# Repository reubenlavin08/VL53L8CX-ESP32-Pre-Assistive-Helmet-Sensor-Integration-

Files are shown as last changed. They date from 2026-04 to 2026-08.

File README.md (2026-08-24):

<h1 align="center">Assistive Helmet</h1>

<p align="center">
  <em>A helmet that answers what the white cane can't: what's at head height, what's approaching, and where exactly the thing you want is.</em>
</p>

<p align="center">
  
  
  
  
  
</p>

---

<p align="center">
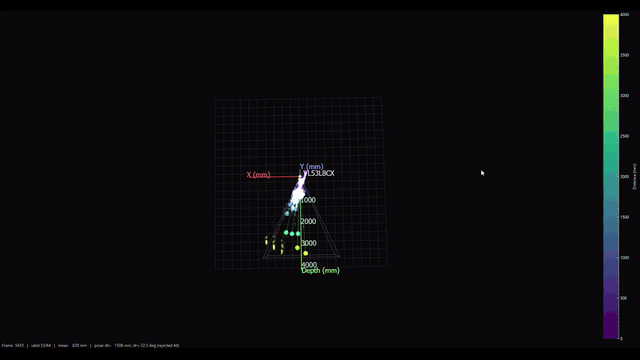
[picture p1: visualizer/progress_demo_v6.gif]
Live 3D depth scan building as the helmet pans
  
</p>
<p align="center"><em>The helmet's two depth sensors building a live 3D scan as the head pans. Demo video of the full system: coming with the field-test release.</em></p>

---

## Why

Blind pedestrians with a cane or a guide dog still take head-level hits — 13% report one at least monthly, and the number is the same for cane and dog users. GPS says "you have arrived" from 5–20 meters away, often on the wrong side of the building. And there is no way to ask the street a question. This helmet is a research prototype aimed at those three gaps. It stays silent until it matters, it never guides anywhere you didn't choose, and the cane stays in charge of the ground.

It is not a mobility aid and not a substitute for a white cane, a guide dog, or O&M training.

## What it does

**Protect** — hazards above cane height, silent by default:
- Tiered voice: nothing → "chair, left" on change → "stop stop" directive that interrupts everything
- Proximity as a tick that speeds with time-to-collision — panned to the hazard's direction — not numbers
- Gravity-referenced head-clearance watch: "low clearance, duck" computed in the world frame from live IMU attitude, so it works mid-stride at any head pitch
- Three temple motors with a walkable-corridor mode: silence when centered, pulses only as you drift toward a wall
- Speech gates itself during fast head turns (a stale "left" mid-scan is worse than silence)
- If the helmet falls, it says so and repeats until picked up

**Guide** — to a target you choose, never a guess:
- "scan doors" → "door one, twelve o'clock, about six steps; door two…" → pick one → Microsoft Soundscape's actual audio beacon (their open-sourced assets) leads you, arrival melody at one meter
- "find exit" → OCR scans as you pan, locks the beacon on the matched word in world coordinates — it keeps working when you look away
- Distances spoken in your calibrated steps, not meters

**Answer** — on demand only:
- "what's around" → one item per sector, terse; ask again for ranges; a third time for a full scene description
- "describe" / "what's in my hand" → a vision-language model answers in one sentence, and says "I can't see that clearly" rather than guess — blind users can't detect a wrong answer, so the system never bluffs
- "read that" → speaks the dominant text in view
- All of it by voice (wake word "Iris"), keyboard, or a double-tap on the shell

**The Iris phone app** — the whole rig is monitored and driven from a phone
with zero App Store involvement: a PWA (`Add to Home Screen` in Safari)
that launches fullscreen under its own icon. Live annotated video at max
size with translucent controls placed in the letterbox space, a status bar
showing what Iris last said, and touch buttons (around / describe / mute /
flag) feeding the same command queue as voice. An always-on launcher
(`camera/launcher.py`, runs at login) means the icon works even when the
software isn't running — it shows a Start button, boots the whole stack,
and hands over to the live view. The desktop window mirrors the same UI.

## The numbers

| What | Measured |
|---|---|
| ToF↔camera extrinsic calibration | 5.5 mm rms, 1.15° from CAD, 39 poses |
| Full CV pipeline on the field laptop | 27 fps segmentation, 114 ms open-vocabulary door scan |
| Scene OCR (cloud) | 1.3–2.4 s, per-word bearings |
| Scene description (cloud VLM) | 2–6 s, abstention-prompted |
| Head-turn gate estimator | tracks 191°/s, decays to 0 on stop |
| False positives | logged per session as FP/hour — the metric that kills devices like this |

## How it works

Two $6 ST VL53L8CX time-of-flight sensors (seam-abutted for a ~90° depth field) and a fisheye camera on a bike helmet, an ESP32-S3 streaming depth + IMU attitude over WiFi, and a laptop fusing it: YOLO segmentation ranges each object by the depth zones its mask claims; an open-vocabulary detector finds doors on demand; cloud models handle text and description. Output is a tier engine modeled on assistive-audio research — Microsoft Soundscape's design language, fighter-aviation callout structure, bat-inspired time-to-collision coding — through open-ear audio and temple haptics. Every alert, override, and near-miss is logged; a hush within ten seconds of an alert counts as a false-positive vote against it.

## Built on evidence

- 30+ commissioned research syntheses in [`docs/research-sources/`](docs/research-sources) — what blind users actually ask for, why every commercial wearable in this space died, and the implementation literature feature by feature
- Design constants read from [Microsoft Soundscape's source](docs/soundscape-reference), not its marketing; competitor patents (.lumen, Glidance, Toyota, Apple) mined for their engineering
- Methods published as prior art so they stay free: [defensive publication](docs/DEFENSIVE-PUBLICATION.md)
- The full build story, failures first: [`docs/DEVLOG.md`](docs/DEVLOG.md)

## Honest limitations

Glass is invisible to the depth sensors (the cane covers it — by design). Bright-sun range is untested and probably poor. Overhead coverage leans on natural gait pitch with the current sensor aim. Cloud features need connectivity (the field rig runs on a phone hotspot). One wearer so far.

Parts of the research synthesis and code were built with Claude as an engineering copilot; every measurement and design decision above was verified on the bench.

---

# Technical reference

## What it does

An ESP32-S3 talks to an **ST VL53L8CX** time-of-flight sensor over I²C, uploads ST's ULD firmware to the chip on boot, and streams the 64-zone depth grid as compact `DATA:d0,d1,…,d63\n` lines over USB-serial at 15 Hz. A Python visualiser reads those lines and renders the scene live — animated ToF rays from the sensor body, a side colour-bar with the distance scale, a Kabsch-based 6-DOF pose estimator, and a world-frame point memory that builds a rolling 3D scan as the sensor sweeps.

---

## Iteration gallery — v1 → v6 at a glance

<table align="center">
  <tr>
    <td align="center" width="25%">
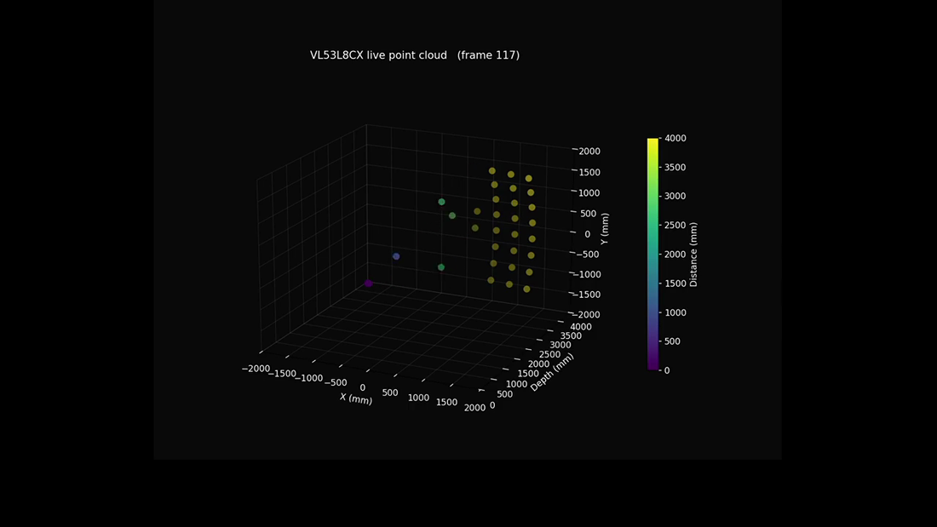
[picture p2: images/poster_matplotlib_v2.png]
v1/v2 matplotlib
      
      <br/><strong>v1 / v2 — matplotlib</strong>
      <br/><sub>first scatter; flicker / drift fixed by v2</sub>
    </td>
    <td align="center" width="25%">
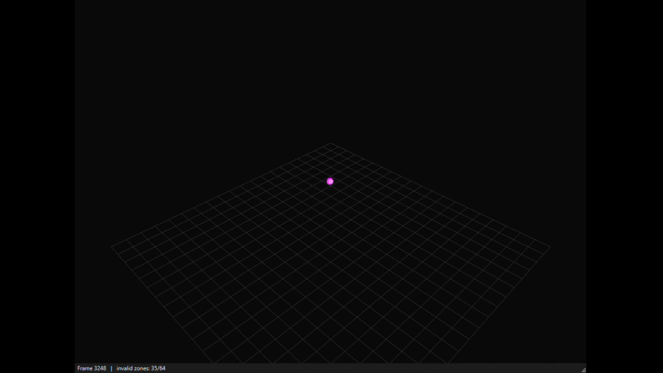
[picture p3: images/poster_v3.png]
v3 PyQtGraph
      
      <br/><strong>v3 — PyQtGraph + threaded</strong>
      <br/><sub>GPU rotation; drain-first pipeline</sub>
    </td>
    <td align="center" width="25%">
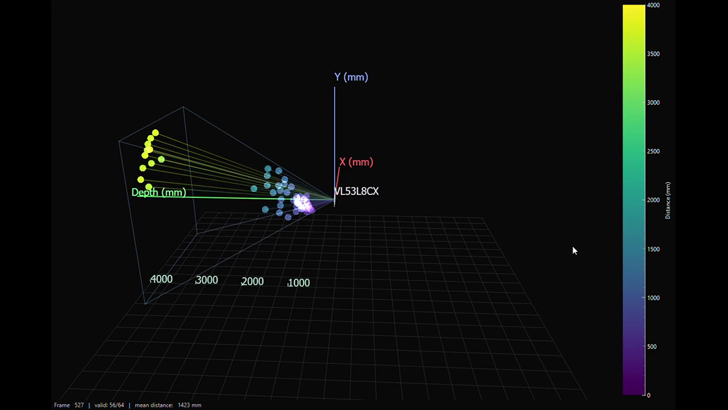
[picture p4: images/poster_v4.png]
v4 scientific look + ToF beams
      
      <br/><strong>v4 — scientific look + ToF beams</strong>
      <br/><sub>colour bar, axes, sensor body, frustum</sub>
    </td>
    <td align="center" width="25%">
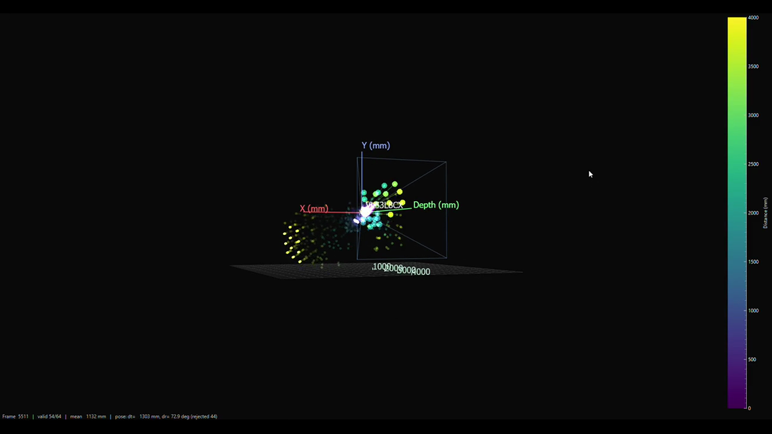
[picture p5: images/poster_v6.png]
v6 world-frame memory
      
      <br/><strong>v6 — world-frame memory</strong>
      <br/><sub>+ Kabsch 6-DOF pose, fading trail</sub>
    </td>
  </tr>
</table>

---

## The hardware

<p align="center">
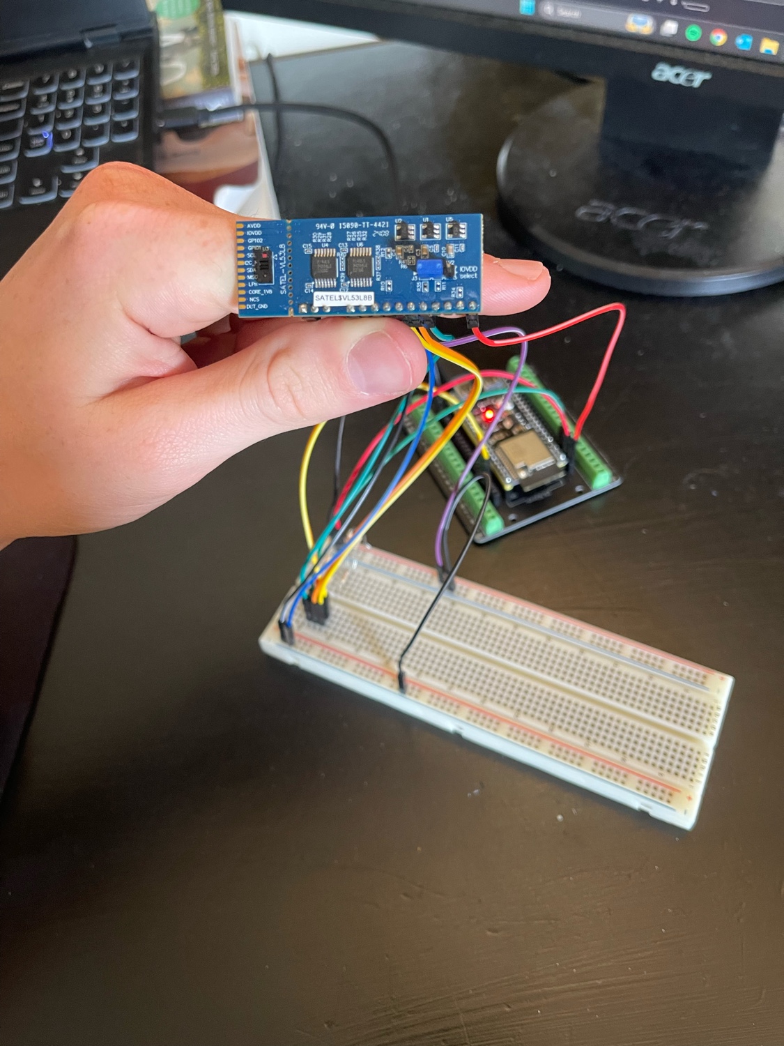
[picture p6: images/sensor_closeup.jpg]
SATEL-VL53L8CX close-up
  
  &nbsp;&nbsp;
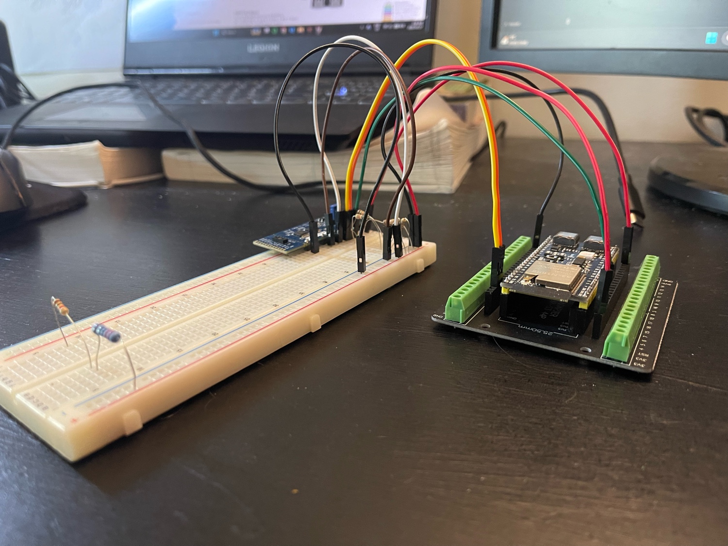
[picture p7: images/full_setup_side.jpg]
Breadboard side view
  
</p>
<p align="center">
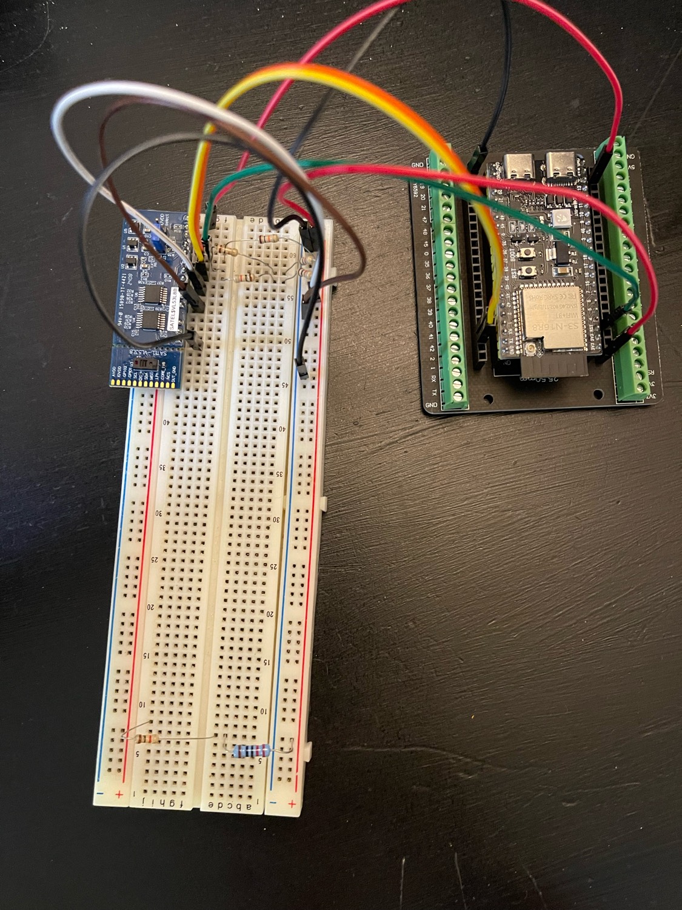
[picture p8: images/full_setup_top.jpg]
Full circuit top-down
  
</p>
<p align="center"><em>SATEL-VL53L8CX breakout on an ESP32-S3-DevKitC-1. 2 × 1 kΩ pull-ups in series on each I²C line, 10 kΩ on PWREN, sensor powered from 3.3 V.</em></p>

---

## The transformation — matplotlib → PyQtGraph

The visualiser was rewritten three times in a single weekend. The first cut used matplotlib `mplot3d`; mouse rotation was sluggish and the renderer was always one frame stale. v3 swapped in PyQtGraph + OpenGL, threaded the serial reader, and flipped the drain order. The clip below is 3 seconds of the original, then 7 seconds of v3:

<p align="center">
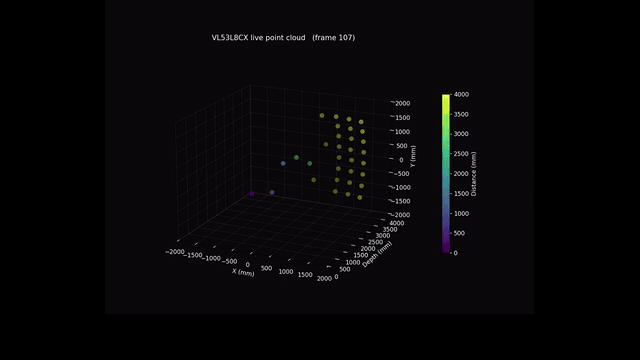
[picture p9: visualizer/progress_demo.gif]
matplotlib v2 vs PyQtGraph v3 before/after
  
</p>
<p align="center">
  <em>Before / after — the same data on the same hardware, rendered through two different pipelines.</em>
  <br/>
  <sub><a href="visualizer/progress_demo.mp4">▶ HD MP4 (10 s, 134 KB)</a></sub>
</p>

| | v1 / v2 (matplotlib) | v3 (PyQtGraph) |
|---|---|---|
| Renderer | software-rendered `mplot3d` | GPU `GLViewWidget` + OpenGL |
| Mouse rotation | sluggish (GUI thread starved) | native — pan/zoom decoupled from data |
| Serial read | on GUI thread; 1 s timeout could stall | dedicated `QThread` with Qt signal |
| Drain order | read → process → drain (always one stale) | drain first, render newest valid frame |
| Smoothing | EMA α = 0.3 (~900 ms settle) | EMA α = 0.6 (~300 ms settle) |
| Invalid zones | drawn as a phantom 4 m back-wall | masked to NaN, drawn transparent |

---

## Architecture

```mermaid
flowchart LR
    A[VL53L8CX SPADs<br/>8×8 zones] -- I²C @ 1 MHz --> B[ESP32-S3<br/>ESP-IDF firmware]
    B -- USB-serial<br/>DATA:… 15 Hz --> C[Python<br/>SerialReader QThread]
    C --> D[Kabsch<br/>pose estimator]
    C --> E[EMA + NaN mask]
    D --> F[PyQtGraph + OpenGL<br/>GLViewWidget]
    E --> F
    F --> G[Live 3D scene<br/>+ world-frame memory]
```

---

## What you're looking at

<p align="center">
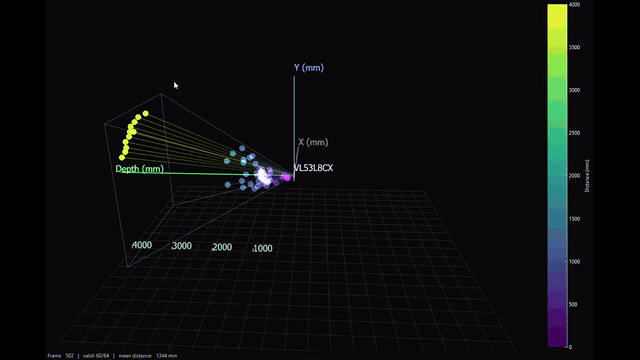
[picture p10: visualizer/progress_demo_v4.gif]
v4 visualiser elements in motion
  
</p>
<p align="center">
  <em>v4 in motion — sensor body, FoV frustum, animated ToF beams. Same scene as v6 but without the world-frame memory layer, so each element is easier to identify in isolation.</em>
  <br/>
  <sub><a href="visualizer/progress_demo_v4.mp4">▶ HD MP4 (5 s, 182 KB)</a></sub>
</p>

| Element | What it is |
|---|---|
| **64 bright dots in a cone** | Live measurements, one per zone, coloured by distance (viridis: purple = close, yellow = far). |
| **Animated coloured beams from the sensor** | One ToF ray per zone, faded from the lens out to its endpoint, in the same hue as the point. They pulse with the live data — physically what a multizone ToF sensor is doing. |
| **Faded surrounding cloud** *(v6)* | Past observations in **world frame**, transformed back into the current sensor frame each tick and faded by age (~6 s memory). As you rotate, they slide off to the side instead of staying glued to the front. |
| **Yellow line behind the sensor** *(v5+)* | Estimated 6-DOF trajectory of the sensor's origin (last ~5 s), per-vertex alpha-faded so old segments disappear. |
| **Sensor body + lens ring at origin** | Flat dark rectangle modelling the SATEL-VL53L8CX face, with a bright lens circle and "VL53L8CX" label. |
| **Pale frustum** | The sensor's actual 45° × 45° field of view (per ST datasheet — 65° diagonal). |
| **Side colour bar** | Distance scale in mm. |
| **Status bar** | Live frame count, valid-zones / 64, mean valid distance, cumulative pose translation + rotation, and the per-frame rejection count. |

---

## Iteration story — v1 → v6

| Version | What it added | Why |
|---|---|---|
| **v1** | First working matplotlib 3D scatter. | Get *anything* on screen. |
| **v2** | In-place scatter update; serial-buffer drain; EMA smoothing. | Killed flicker, stale data, noise jitter. |
| **v3** | PyQtGraph + OpenGL; threaded serial; drain-first; α = 0.6; invalid-zone mask. | Fixed mouse-drag lag and one-frame-stale render. |
| **v4** | Side colour bar; X / Y / Depth axes; sensor body; FoV frustum; **animated ToF beams**. | Restored the "scientific" look + made the physics legible. |
| **v5** | **Kabsch / Procrustes 6-DOF relative pose estimator** with sanity gates and a trajectory trail. | First motion estimate from depth alone, no IMU. |
| **v6** | World-frame point memory (~6 s) re-projected each tick into the current sensor frame; per-vertex alpha-faded trail. | Makes the point cloud wrap around the sensor as it rotates instead of being glued to the front cone. |

For the full development log — every problem hit, every fix and the evidence behind it, every dead end — see [`PROGRESS.md`](PROGRESS.md).

---

## How the visualiser works

### Serial protocol
The ESP32 streams one compact line per frame:
```
DATA:820,815,801,790,...,(64 values total)
```
Invalid zones are clamped to `MAX_DISTANCE_MM` (= 4000 mm) on the firmware side, so the host always gets exactly 64 values. The visualiser detects the clamp and renders those zones with `α = 0`, hiding them. ESP_LOG lines in the same stream don't start with `DATA:` and are simply ignored by the parser.

### Threaded read pipeline
Serial reads run in a dedicated `QThread`; new frames are delivered to the GUI via a Qt signal. Each cycle drains everything currently buffered and keeps only the **newest** valid `DATA:` line — which kills the "rendering one frame stale" failure mode of the original `read → process → drain` order.

### Geometric projection
The VL53L8CX is **65° diagonal / 45° per axis**. Each of 8 zones along an axis subtends `45° ÷ 8 = 5.625°`. A unit direction vector is precomputed for every zone:

```text
h_angle = (col − 3.5) × 5.625°       v_angle = (row − 3.5) × 5.625°
x =  sin(h_angle)
y = −sin(v_angle)                     (row 0 is the top of the sensor view)
z =  cos(h_angle) × cos(v_angle)      (sensor boresight = +Z)
```

Multiplying each unit vector by its zone's measured distance gives the 3D point in the sensor's body frame.

<p align="center">
  Live 3D point cloud — frame 1916, pointing at a wall ~1800 mm away
</p>
<p align="center"><em>First-light static screenshot — frame 1916, sensor pointed at a wall ~1800 mm away.</em></p>

### EMA smoothing
Raw zones jitter ±10–30 mm frame-to-frame on a static scene. Per-zone exponential moving average:

```python
smoothed[v] = 0.6 * new[v] + 0.4 * smoothed[v]
```

α = 0.6 settles to 95 % of a step input in `−ln(0.05) ÷ −ln(1 − 0.6) ≈ 3` samples — about 200 ms at 15 Hz.

### 6-DOF relative pose (Kabsch / Procrustes)

Closed-form rigid registration on consecutive 64-point clouds. Given paired sets P (frame k−1) and Q (frame k):

```text
1.  Pc, Qc      = P − mean(P), Q − mean(Q)
2.  H           = Pc.T @ Qc
3.  U, S, Vt    = svd(H)
4.  d           = sign(det(Vt.T @ U.T))         # reflection guard
5.  R           = Vt.T @ diag(1, 1, d) @ U.T
6.  t           = mean(Q) − R @ mean(P)
```

The fitted (R, t) maps a world point's old-frame coords to its new-frame coords. The **sensor's** per-frame motion is the inverse: `δR = R.T`, `δt = −R.T @ t`. World-frame cumulative pose composes as `T_world(k) = T_world(k-1) · δ`.

Same-zone correspondence relies on the small-motion assumption — at 15 Hz (~67 ms per frame) zone *i* in two consecutive frames still observes approximately the same world point. Wrong correspondence (fast motion) shows up as huge fitted Δt or ΔR; the estimator gates on `≤ 300 mm` and `≤ 20°` per frame and breaks the chain instead of corrupting cumulative state.

### World-frame point memory (v6)

Each frame, valid sensor-frame points are transformed via `world_p = R_world · sensor_p + t_world` and pushed into a rolling 6-second deque. For rendering, every entry is transformed *back* into the current sensor frame and given an alpha proportional to its age (newest = ~0.35, oldest = 0). The visual effect: as the sensor pans, old observations stay fixed in space and slide around — the "cone" effectively wraps around.

### Limitations

- 64 points × ±10–30 mm noise is sparse and noisy for ICP-style registration. Expect drift, especially in **yaw** (rotation around gravity is unobservable from a flat-floor depth map — no algorithm can recover it from depth alone).
- 0/64 valid zones (covered sensor, loose connection) → estimator pauses cleanly.
- The 6-second memory cap keeps drift damage local. With an IMU added later, the same code becomes a usable sparse 3D map.

---

## Quick start

```bash
# 1. Firmware  (ESP-IDF v5.0+, tested on v5.4.4)
cd vl53l8cx_esp32
idf.py set-target esp32s3
idf.py -p COM12 flash         # adjust COM port for your machine

# 2. Visualiser (in a separate terminal — flash/monitor must be closed)
cd visualizer
python -m venv venv && venv\Scripts\activate
pip install -r requirements.txt
python visualizer.py --port COM12
```

| Visualiser flag | Default | Description |
|---|---|---|
| `--port` | `COM12` | Serial port the ESP32 is on |
| `--baud` | `115200` | Matches the ESP-IDF console default |
| `--max-mm` | `4000` | Z-axis range + colour-scale max (mm) |

**Hotkey:** press **`R`** in the visualiser window to reset the cumulative pose and clear the trail + accumulated cloud.

---

## Wiring

### Sensor (SATEL-VL53L8CX)

| SATEL pin | ESP32-S3 pin | Pull-up |
|---|---|---|
| `PWREN` | GPIO 5 | 10 kΩ → 3.3 V |
| `MCLK_SCL` | GPIO 2 | 2 × 1 kΩ in series → 3.3 V |
| `MOSI_SDA` | GPIO 1 | 2 × 1 kΩ in series → 3.3 V |
| `NCS` | 3.3 V | tied high (selects I²C) |
| `SPI_I2C_N` | GND | tied low (locks I²C) |
| `VDD` | 3.3 V | (LDO accepts 2.8–5.5 V) |
| `GND` | GND | — |

> Pull-up resistors connect **between the signal line and 3.3 V**, not in series along the wire. Power the sensor from 3.3 V — not 5 V. Use the **UART USB port** (left, on DevKitC-1) for flashing.

### Actuators (alert outputs)

| Signal | ESP32-S3 pin | Driver | Notes |
|---|---|---|---|
| Buzzer | GPIO 6 | direct (drive cap 3, ~40 mA) | active 5 V piezo, `+` → GPIO 6, `−` → GND |
| Haptic motor — **CENTER** (forehead) | **GPIO 7**  | 1 kΩ → 2N3904 NPN base; collector → motor → 3V3; emitter → GND | LEDC ch 1 / timer 1 @ 1 kHz |
| Haptic motor — **RIGHT** temple | **GPIO 15** | same driver | LEDC ch 2 / timer 1 |
| Haptic motor — **LEFT** temple | **GPIO 16** | same driver | LEDC ch 3 / timer 1 |

> Mapping verified 2026-05-28 with the `HAPTIC_ID_MODE` single-pin pulse test (one motor pulses every 3 s, user reports which physical location buzzes). Aliases `HAPTIC_GPIO_CENTER` / `_RIGHT` / `_LEFT` defined in `main.c` so column→motor mapping reads geographically rather than by wiring order.

The buzzer owns LEDC channel 0 / timer 0; haptic motors share timer 1 across channels 1–3 so they can be driven independently from the same PWM frequency source. Motors are 70 Ω ERM coin (~43 mA stall each at 3 V) — well within a 2N3904's 200 mA Ic. Schottky 1N5819 flyback diodes (cathode → 3V3) and a 100 µF bulk cap across the 3V3 rail are recommended for the final perfboard build but were proven unnecessary for bench validation on the dev-board regulator. `main.c` forces all three motor GPIOs to OUTPUT-LOW with a pulldown at the start of `app_main` — guarantees no stuck-on motor across reboots regardless of build configuration.

<details>
<summary><strong>Configuration knobs (firmware)</strong></summary>

Edit the defines at the top of [`main/main.c`](main/main.c):

| Define | Default | Options |
|---|---|---|
| `GPIO_SDA` / `GPIO_SCL` / `GPIO_PWREN` | 1 / 2 / 5 | any valid GPIO |
| `SENSOR_RESOLUTION` | `VL53L8CX_RESOLUTION_4X4` *(was 8X8 prior to v7)* | `_8X8`. 4×4 = 16 zones with 4× more SPADs per zone (~4× lower per-zone noise per the v9 sweep); 8×8 = 64 zones with finer spatial detail but ~4× higher per-zone noise. |
| `RANGING_FREQ_HZ` | `30` *(was 15 / 10 / 8 in earlier iterations)* | 1–15 Hz at 8×8, 1–60 Hz at 4×4. Wearable-latency analysis (see `docs/research-optimal-config.md` Phase 1) showed frame latency dominates per-zone noise by 10–40× for a moving user — picked 30 Hz over 10 Hz for the reaction-time gain. 60 Hz worth empirical testing. |
| `HAPTIC_TEST` | `0` | `1` runs the 3-motor bench/identify test instead of the sensor pipeline (WiFi + OTA stay up either way). See v11. |
| `HAPTIC_ID_MODE` | `0` | When `HAPTIC_TEST=1`, set to `1` to pulse only `HAPTIC_ID_GPIO` for physical-motor identification. |
| `RANGING_MODE` | `VL53L8CX_RANGING_MODE_CONTINUOUS` | `_AUTONOMOUS` to set integration time explicitly |
| `STREAM_DATA` | `1` | `0` to silence the `DATA:` lines |
| `STREAM_SIGMA` | `1` | `0` to silence the `SIGMA:` lines (v7+) |
| `PRINT_GRID` | `0` | `1` for the ASCII 8×8 grid |
| `PRINT_CLOSEST_ONLY` | `0` | `1` for nearest-zone log only |
| `MAX_DISTANCE_MM` | `4000` | clamp value for invalid zones |
| `BUZZER_TEST` | `1` | obstacle-alert buzzer task (v8+); `0` to compile out |
| `BUZZER_GPIO` | `GPIO_NUM_6` | active-buzzer signal pin (v8+) |
| `OBSTACLE_THRESHOLD_MM` | `600` | buzzer triggers when any zone < this (v8+) |
| `BEEP_MS` | `50` | beep duration in ms (v8+) |
| `BEEP_GAP_MIN_MS` / `BEEP_GAP_MAX_MS` | `30` / `400` | beep gap at point-blank / at threshold (v8+) |

WiFi + OTA values live in `main/wifi_credentials.h` (gitignored) — see the "Credentials setup" subsection under v7.

</details>

<details>
<summary><strong>Troubleshooting</strong></summary>

| Symptom | Cause | Fix |
|---|---|---|
| Sensor not detected | wiring issue | Check SDA/SCL aren't swapped, pull-ups go to 3.3 V (not in-line). |
| Silent hang after "interface starting" | I²C read timeout = `-1` (infinite) | Already fixed in `sdkconfig.defaults` (`CONFIG_VL53L8CX_I2C_TIMEOUT=y`, value 1000). |
| 5 V pin reads ~2 V | plugged into native USB port | Use the UART port, or power the sensor from 3.3 V (the SATEL LDO accepts 2.8–5.5 V). |
| Stack overflow | main stack too small | Already raised to 8192 bytes in `sdkconfig.defaults`. |
| Visualiser can't open COMxx | `idf.py monitor` is holding it | Close monitor (Ctrl + ]) before launching the Python visualiser. Or use WiFi (`--host`) which doesn't share the port. |
| COMxx vanishes whenever the ESP resets | Native USB-CDC re-enumerates on reset | Use the **UART port** (CH343 → typically COM12 on Windows). The CH343 stays connected to the host regardless of ESP state. The native USB port (typically COM10) drops every time the ESP reboots. The `restart_tools.ps1` script + desktop shortcut handles the relaunch after each reset. |
| OTA push fails with HTTP 401 | wrong/missing `X-OTA-Token` header | Verify `OTA_TOKEN` in `wifi_credentials.h` matches the one in `ota_flash.py`. |
| OTA push fails with timeout / connection refused | ESP not on WiFi, or wrong IP | Re-check the boot log over UART for "Got IP: x.x.x.x". DHCP may have changed it. |
| Build fails | wrong IDF version | Requires ESP-IDF v5.0+ (developed against v5.4.4). |

</details>

---

## Project layout

```
vl53l8cx_esp32/
├── main/
│   ├── main.c                  # sensor init, ULD upload, ranging loop, DATA:/SIGMA: streaming, WiFi STA, TCP server (3333), OTA HTTP server (80)
│   ├── wifi_credentials.h      # SSID / password / OTA token (GITIGNORED — never committed)
│   ├── CMakeLists.txt          # component dependencies (esp_wifi, lwip, app_update, esp_http_server, etc.)
│   └── idf_component.yml       # pulls rjrp44/vl53l8cx ^4.0.0 automatically
├── visualizer/
│   ├── visualizer.py           # v6 — full PyQtGraph 3D scene with Kabsch pose + world-frame memory
│   ├── visualizer_simple.py    # v7 — stripped-down point cloud, blinker, rays. Serial OR WiFi.
│   ├── pose_estimator.py       # Kabsch/SVD 6-DOF relative pose, gated and composable
│   ├── measure.py              # v7 — tuning measurement: per-zone σ + valid yield, CSV log
│   ├── ota_flash.py            # v7 — push firmware to ESP over WiFi (POST /update)
│   ├── restart_tools.ps1       # v7 — one-click visualizer + monitor restart
│   ├── progress_demo*.gif      # inline-renderable demo clips for the README
│   └── progress_demo*.mp4      # original HD captures (downloadable)
├── images/                     # hardware photos + per-version poster screenshots
├── sdkconfig.defaults          # I²C timeout, raised stack, two-OTA partition layout, 16 MB flash
├── PROGRESS.md                 # full iteration log + every fix and its evidence
└── README.md                   # you are here
```

---

## Known limitations of v6

This project is paused at a deliberate stopping point. Every remaining issue below either needs new hardware or is an inherent property of the sensor — none are software defects that another rewrite would fix. Each item is documented with its root cause and what would resolve it:

- **Yaw drifts continuously.** Rotation around gravity is fundamentally unobservable from a flat-floor depth map — the same wall looks the same from every yaw angle. The Kabsch estimator fills the gap with whatever the noise suggests and accumulates error. Visible as the trail and accumulated cloud slowly rotating relative to a stationary scene over ~30 s.
- **All-axis drift over time, even on a static scene.** With ±10–30 mm per-zone noise and only 64 points, every frame's pose estimate has a small bias. Over a few hundred frames that integrates into a noticeable offset. The 6-second memory cap exists specifically because anything older than that is too drifted to be useful.
- **Same-zone correspondence breaks under fast motion.** The estimator assumes zone *i* in two consecutive frames sees roughly the same world point. A quick wave of the hand can shift several zones onto entirely different objects in one 67 ms tick — the gates (`≤ 300 mm`, `≤ 20°` per frame) catch this and the cumulative pose just *pauses*. Useful behaviour (better than corrupting the chain), but you'll see frames where the trail simply doesn't update.
- **Accumulated point cloud smears, not snaps.** When pose drifts, world-frame points from old frames end up at slightly wrong world coordinates. Returning the sensor to a previously-scanned region produces a "ghosted" cloud rather than perfect overlap. There is no loop closure.
- **64 points is genuinely sparse.** A consumer depth camera gives ~300 000 points per frame; this gives 64. ICP-style methods are noticeably less stable with this density. The visual effect is correct, but anyone expecting Kinect-grade scanning quality should know this is two orders of magnitude away from that.
- **EMA introduces a 200 ms tail.** Even at α = 0.6, the smoothed reading is ~200 ms behind a fast scene change. You'll see this when an object enters the FoV — the points snap into place over ~3 frames rather than instantly. Tradeoff for noise rejection; lowering α makes the points jitter visibly on a static scene.
- **Power glitches / loose connections silently produce 0/64-valid frames.** When that happens, every zone clamps to 4 000 mm and renders transparent — the cone "goes dark" with no error popup, just a status-bar reading of `valid 0/64 | pose paused`. This was hit several times during development (see [`PROGRESS.md`](PROGRESS.md) issue #6).
- **Sensor cover glass / fingerprints / tilt-induced specular drop matter.** A smudge or a steep angle on a glossy surface drops valid-zone count to a handful, which both starves the live cloud and kills the pose estimator's correspondence count below its 6-point threshold.

The fix for the first four items is the same: **add an IMU**. A 6-axis MPU-6050 / LSM6DSO on the same I²C bus gives gravity (absolute pitch / roll, no drift), gyro rate (yaw integration with accel-gravity correction, far less drift than depth-only), and a hardware-level timing reference. None of these can come from the VL53L8CX alone, no matter how good the algorithm is. The remaining items are sensor-physics ceilings that no software change can move.

---

## v7 — Untethered: WiFi streaming + OTA reflashing

Phase-1 firmware improvements (no algorithm changes — the sensor pipeline itself is unchanged from v6). The point of v7 is to cut the USB cable for two operations: **streaming data** and **flashing firmware**. Both now happen over WiFi.

### What changed

- **Per-zone `range_sigma_mm` is now also streamed.** Each frame the ESP emits a `SIGMA:s0,s1,…,s63\n` line right after the existing `DATA:` line. The sigma values are the ULD's on-chip per-measurement uncertainty estimate (in mm). Hosts can use them as a real-time quality flag and as a sanity check against an externally-computed σ.
- **Status filter widened from `{5}` to `{5, 6, 9}`.** Status 5 = 100 % confidence; 6 = wrap-around-not-done (still valid at sub-4 m range); 9 = low signal but range valid. The wider filter raises valid yield on dim or angled surfaces. (Per ST UM3109 §5.5.)
- **WiFi station mode + single-client TCP server on port 3333.** The same `DATA:` / `SIGMA:` lines are written to both UART AND any TCP client that connects. UART keeps working as a fallback.
- **OTA firmware updates over WiFi.** Two-OTA partition layout. A small HTTP server on port 80 accepts `POST /update` with an `X-OTA-Token` header; the body is streamed into the inactive partition, finalised, and booted into on reboot. After the first manual USB flash, every subsequent flash is wireless.
- **Credentials never enter the repo.** SSID, password, and OTA token live in `main/wifi_credentials.h`, which is gitignored. The file is created from the template `main/wifi_credentials.h.template` when cloning fresh.
- **Sensor-init-before-WiFi ordering.** WiFi current spike on boot can brown the sensor's 5V rail; the ranging task is started first and given a 2.5 s head start before the WiFi stack comes up.

### v7 architecture

```mermaid
flowchart LR
    A[VL53L8CX SPADs<br/>8×8 zones] -- I²C @ 1 MHz --> B[ESP32-S3<br/>ESP-IDF firmware]
    B -- USB-serial<br/>DATA: SIGMA:<br/>(fallback) --> C1[Host scripts<br/>serial reader]
    B -- TCP :3333<br/>DATA: SIGMA: --> C2[Host scripts<br/>TCP reader]
    B -. HTTP :80<br/>POST /update .-> B
    C1 --> V[visualizer.py · visualizer_simple.py]
    C2 --> V
    C1 --> M[measure.py<br/>tuning stats + CSV]
    C2 --> M
    H[ota_flash.py<br/>idf.py build first] -. HTTP POST .-> B
```

### New host-side tools

| Tool | Purpose |
|---|---|
| `visualizer/visualizer_simple.py` | Stripped-down point cloud (no pose, no trail, no FoV frustum). Adds a status-bar blinker pulsing at the framerate + lines from origin to each measured point. Accepts `--port COMxx` OR `--host <ip>`. |
| `visualizer/measure.py` | Tuning measurement script. Captures N frames, computes per-zone mean / σ / valid yield / mean sensor-sigma. Median σ across zones is the headline metric. Appends CSV — one row per zone per run. Accepts `--port` OR `--host`. |
| `visualizer/restart_tools.ps1` | One-click PowerShell script that kills any running visualizer + monitor and relaunches both. Companion desktop shortcut (`Restart ESP Tools.lnk`). Workaround for the ESP32-S3 native USB-CDC dropping COM enumeration on every reset. |
| `visualizer/ota_flash.py` | Pushes `build/vl53l8cx_esp32.bin` to the ESP via `POST http://<ip>/update` with the X-OTA-Token header. Workflow: `idf.py build` then `python visualizer/ota_flash.py` — done in seconds, no cable. |

### Quick start — wired vs wireless

```bash
# Wired (first time, also the only USB flash needed)
idf.py -p COM10 flash
python visualizer/visualizer_simple.py --port COM10        # serial point cloud
python visualizer/measure.py --port COM10 --frames 200 \
       --config "baseline-15hz-8x8"

# Wireless (after first flash; no USB needed)
python visualizer/visualizer_simple.py --host 192.168.1.228
python visualizer/measure.py --host 192.168.1.228 --frames 200 \
       --config "baseline-15hz-8x8-wifi"
idf.py build && python visualizer/ota_flash.py 192.168.1.228   # OTA reflash
```

### Credentials setup (first-time clone)

The file `main/wifi_credentials.h` is **not in the repo**. Copy the template and fill in your values:

```c
#pragma once
#define WIFI_SSID     "<your-network>"
#define WIFI_PASSWORD "<your-password>"
#define TCP_PORT      3333
#define OTA_HTTP_PORT 80
#define OTA_TOKEN     "<pick-a-random-token>"     // must also live in ota_flash.py
```

The OTA token is what `ota_flash.py` sends in the `X-OTA-Token` header — keep both copies in sync.

### Gotcha if you change the partition table or flash size mid-project

`sdkconfig.defaults` only takes effect when `sdkconfig` is generated **for the first time**. If you change a value in `sdkconfig.defaults` after `sdkconfig` already exists, the change is ignored — the existing `sdkconfig` wins. Symptom (seen during v7 dev): OTA push fails with `esp_ota_get_next_update_partition()` returning NULL because the partition table is still `SINGLE_APP` instead of `TWO_OTA`. Fix:

```bash
rm sdkconfig          # delete and let it regenerate from sdkconfig.defaults
idf.py build          # rebuilds sdkconfig + new partitions + ota_data_initial.bin
idf.py -p COM10 flash # USB-flash one more time to install the new layout
```

After that one manual flash, OTA pushes work for all subsequent firmware iterations.

---

## v8 — First sensor → actuator loop (obstacle alert)

Phase-1 functional milestone: the sensor now drives an output. The helmet now actively *signals* what it sees rather than just streaming numbers.

### What's new

- **Active buzzer on GPIO 6** with a dedicated FreeRTOS task. Drive strength bumped to `GPIO_DRIVE_CAP_3` (~40 mA) so the active buzzer's current draw doesn't collapse the GPIO voltage. Stack 4096 bytes (2048 was overflowing — see "Lessons" below).
- **Nearest-zone tracker:** every ranging frame, the ranging task scans all 64 (or 16) zones, finds the minimum valid distance, and publishes it as `g_nearest_mm` (atomic 16-bit volatile, no mutex needed on ESP32-S3).
- **Distance-proportional beep rate:** the buzzer task polls `g_nearest_mm` at 10 Hz and only beeps when something is closer than `OBSTACLE_THRESHOLD_MM` (60 cm default). Beep gap interpolates linearly between `BEEP_GAP_MAX_MS` (slow alert at threshold) and `BEEP_GAP_MIN_MS` (frantic chirping at point-blank). Closer = faster = more urgent. Classic obstacle-alert UX.
- **Beep duration `BEEP_MS` = 50 ms** — short pulse is audibly quieter than the previous 200 ms while still being noticeable.

### Wiring

| Pin | Connection |
|---|---|
| GPIO 6 (board silkscreen `6` on TOP of LEFT header) | Active buzzer `+` |
| GND | Active buzzer `−` |

The buzzer can sit on the same dev board headers as the sensor — they share nothing.

### Configuration knobs

| Define | Default | Notes |
|---|---|---|
| `BUZZER_TEST` | `1` | set `0` to compile out the buzzer task entirely |
| `BUZZER_GPIO` | `GPIO_NUM_6` | move to another free GPIO if needed |
| `OBSTACLE_THRESHOLD_MM` | `600` | start beeping at this distance; nothing beyond it counts |
| `BEEP_MS` | `50` | beep duration (shorter = quieter) |
| `BEEP_GAP_MIN_MS` | `30` | gap between beeps at point-blank (0 mm) |
| `BEEP_GAP_MAX_MS` | `400` | gap at threshold distance |

### Lessons from v8 dev

- **Stack-overflow gotcha:** FreeRTOS tasks each get an explicit stack budget at `xTaskCreate(...)`. ESP-IDF's `ESP_LOGI(...)` calls can use 200+ bytes for string formatting alone; plus the `gpio_config_t` struct (~40 B); plus kernel context. **2048 bytes is not enough** even for "trivial" tasks if they log. Default to **4096 bytes** unless you've measured. The chip rebooted in a 2-second loop with the buzzer task at 2048 bytes — every multimeter probe in that period showed the GPIO at 0 V because the pin was only set HIGH for milliseconds at a time before the next reboot.
- **`xTaskCreate` calls go missing in edits.** If your task never logs its startup message, the first thing to check is whether the `xTaskCreate(...)` actually exists in `app_main`.
- **ESP32-S3 active-buzzer current draw exceeds default GPIO drive.** Default drive capability is `GPIO_DRIVE_CAP_2` (~20 mA). Active buzzers often pull 25–30 mA. The pin voltage collapses when overloaded. Fix: `gpio_set_drive_capability(BUZZER_GPIO, GPIO_DRIVE_CAP_3)` to bump it to ~40 mA.
- **AliExpress dev boards labels are usually accurate** — but always verify the silkscreen near the pin (e.g. `IO6`) before assuming. The pins for GPIO 4–7 are at the **TOP** of the LEFT header on the ESP32-S3-DevKitC-1, not the bottom (where 5Vin and GND live).

---

## v9 — Sensor characterization: 17-config × 3-distance sweep + analysis

Going into Phase 1 of the helmet I realised I had no principled answer to "which sensor configuration should I actually fly?" The previous versions used whatever defaults made the visualizer look good. For an obstacle-avoidance device I needed a real basis for picking resolution, frame rate, sharpener, target order, and the status filter. v9 is the firmware + tooling + analysis I built to settle that empirically.

### My test rig

<p align="center">
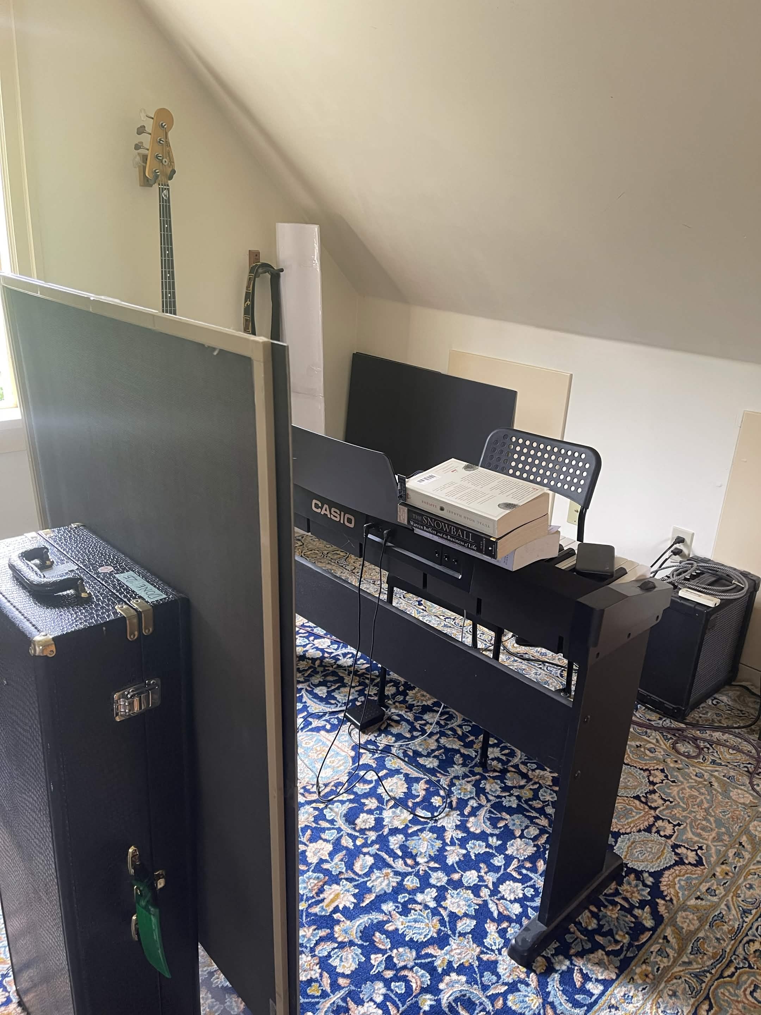
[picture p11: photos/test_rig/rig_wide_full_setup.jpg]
Full test rig — two black foam boards on a music stand, sensor on breadboard on top of a keyboard
  
  &nbsp;
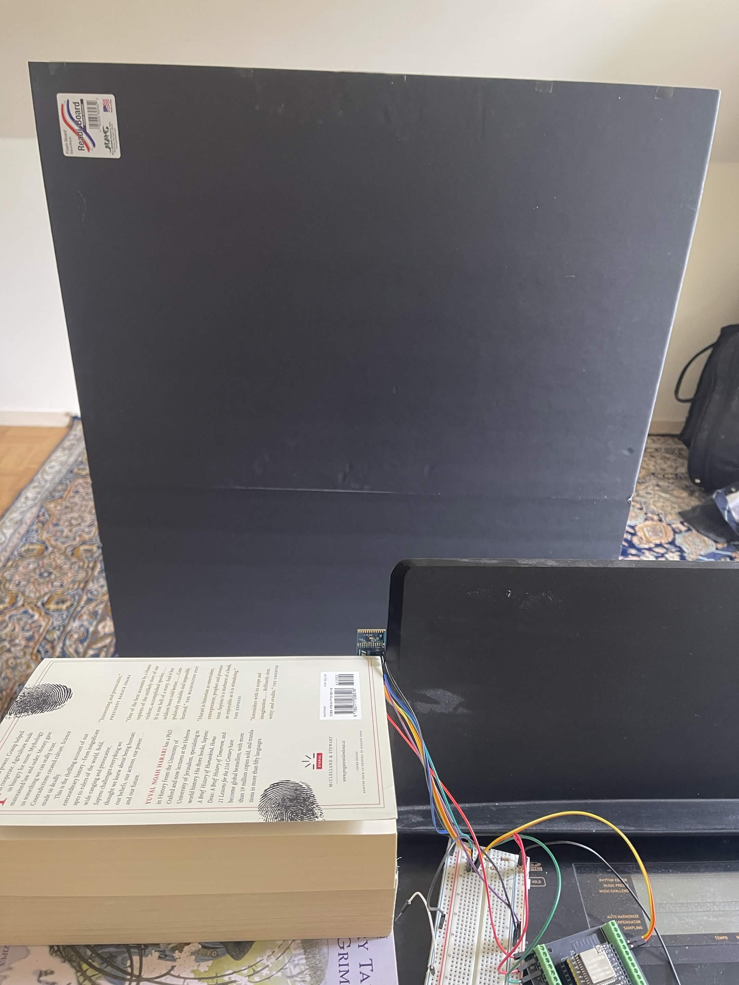
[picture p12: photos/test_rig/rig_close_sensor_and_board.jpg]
Close-up — sensor on breadboard with foam board in front
  
</p>
<p align="center"><em>Two black foam boards (~76 × 122 cm total) raised on a music stand, sensor mounted on a breadboard sitting on top of a digital keyboard at 34.5″ above the floor. Black foam is a worst-case low-IR-reflectance surface — anything that worked here is a baseline for everything brighter.</em></p>

### What I added for the sweep

- **Multi-client TCP fan-out** in the firmware. The previous firmware accepted exactly one TCP client at a time, so I couldn't run my visualizer and `measure.py` simultaneously — connecting one kicked the other off. I rewrote the broadcast layer to hold up to 4 client sockets and `send()` to each per frame with `MSG_DONTWAIT`. A slow client self-evicts when its `send()` returns negative instead of stalling the ranging task.
- **`STATUS:` line streamed per frame**, alongside the existing `DATA:` and `SIGMA:` lines. This gives me the raw ST UM3109 §5.5 status code (0 = no update, 5 = valid, 6 = wrap-around uncertain, 9 = low signal valid, etc.) for every zone every frame. Before this, I only knew whether a zone passed my filter — now I can see *which* failure mode it hit if it didn't.
- **Compile-time `#define` knobs** in `main.c` for `SHARPENER_PERCENT`, `TARGET_ORDER`, `STATUS_FILTER_STRICT`, plus the existing `SENSOR_RESOLUTION` and `RANGING_FREQ_HZ`. Each one wires into the corresponding ULD API call (`vl53l8cx_set_sharpener_percent()`, `vl53l8cx_set_target_order()`). One config = one line edit in `main.c` + one OTA flash.
- **PowerShell sweep runner** (`visualizer/run_sweep.ps1` + `run_one_test.ps1`) that loops over a hardcoded list of 17 configs, patches `main.c`, builds, OTAs, waits for the ESP to come back online, runs `measure.py` for 200 frames, and moves on. 17 configs × 3 distances = 51 captures, unattended.
- **3× retry-on-capture-failure** logic. The ESP's sensor I²C init fails about 20 % of the time after a warm reboot — my best guess is a power-rail dip from the WiFi startup current. When it fails, no `DATA:` lines come out and `measure.py` times out. My retry loop catches that, re-pushes the OTA to force another fresh boot, and tries again. Three attempts catches almost everything (0.2³ ≈ 1 % failure rate).
- **`measure.py` enhancements**: parses the new `STATUS:` line, writes per-zone-per-frame raw data to `raw_frames/`, computes detection-rate against the firmware buzzer threshold, prints the status-code distribution at the end of each run.
- **Analysis script** (`visualizer/analyze.py`) generates the plots in `visualizer/plots/` — σ-vs-distance scaling, config × distance heatmap, knob-impact breakdowns, per-zone σ heatmaps, per-zone mean-distance maps.

### Test methodology

- **17 configs:** A-series = 8×8 at 10/15 Hz × sharpener {0, 5, 20}. B-series = 4×4 at 10/15/30 Hz × sharpener {0, 5, 20}. C1 = STRONGEST target order (vs CLOSEST default). D1 = strict status filter {5 only} (vs default {5, 6, 9}).
- **Three distances:** 48 cm, 68 cm, 89 cm — perpendicular to the foam-board target.
- **200 frames per config**, all per-zone distance + sigma + status written to `raw_frames/` so I can re-analyze later without re-running anything.
- See [`photos/test_rig/test_rig_notes.md`](photos/test_rig/test_rig_notes.md) for the FoV math, the noted ~5–10° downward sensor tilt I eyeballed during setup, and the rest of the rig context.

### Results

#### Figure 1 — Distance noise scaling

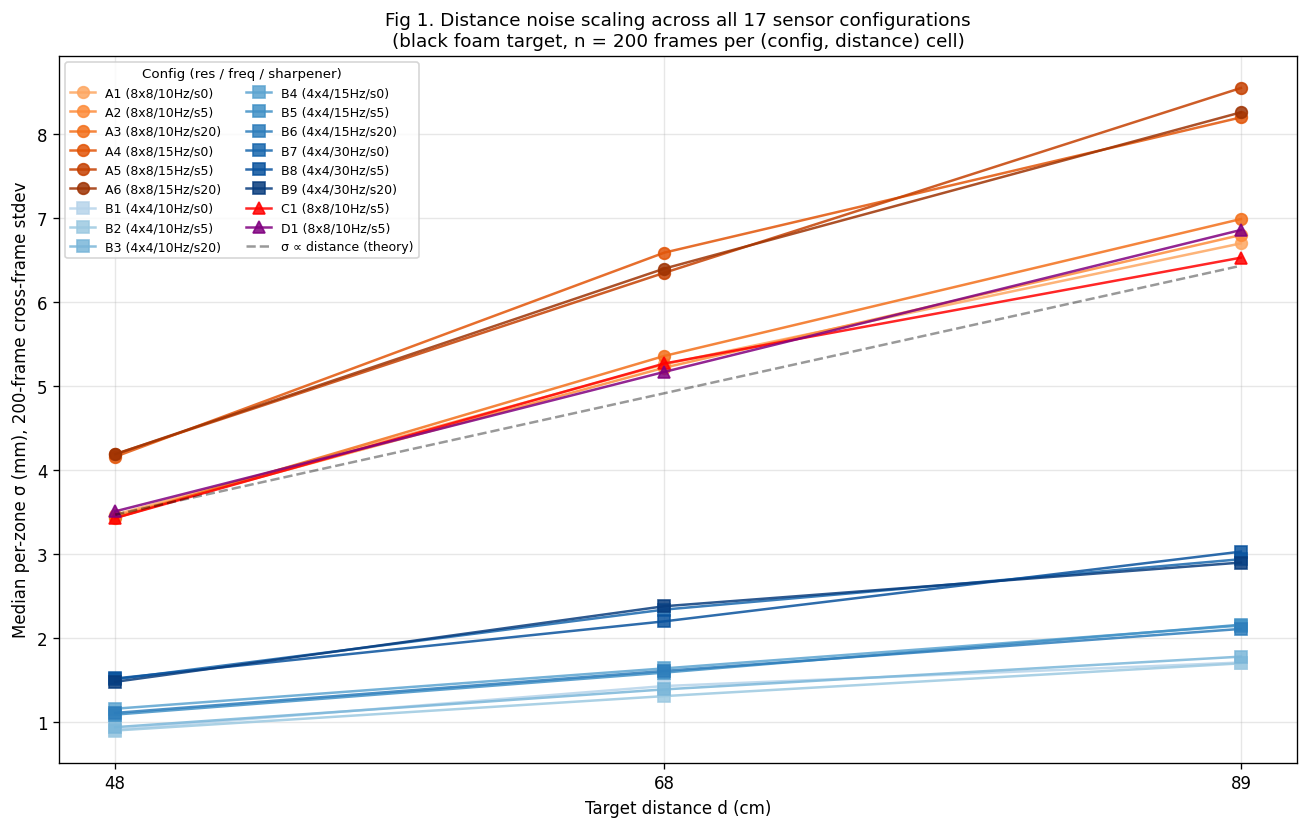
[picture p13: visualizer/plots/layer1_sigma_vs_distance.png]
Fig 1 — sigma vs distance


**What this is:** Median per-zone σ (cross-frame standard deviation over 200 frames) vs target distance, one line per config. The dashed black line is the theoretical `σ ∝ d` prediction anchored at the A1 baseline.

**What I take from it:** All 17 of my configs track the linear prediction cleanly. That confirms the noise floor is **shot-noise-dominated** — N photons per measurement scales as 1/d² for a target filling the sensor's view, and Poisson statistics give σ ∝ 1/√N, so σ ∝ d. This is the physical floor; no firmware tuning of mine can beat it on the same hardware. The clean separation between the orange (8×8) and blue (4×4) families is the second-biggest signal in this plot — at every distance I tested, 4×4 sits at roughly a quarter of the 8×8 noise.

#### Figure 2 — Cross-config noise comparison

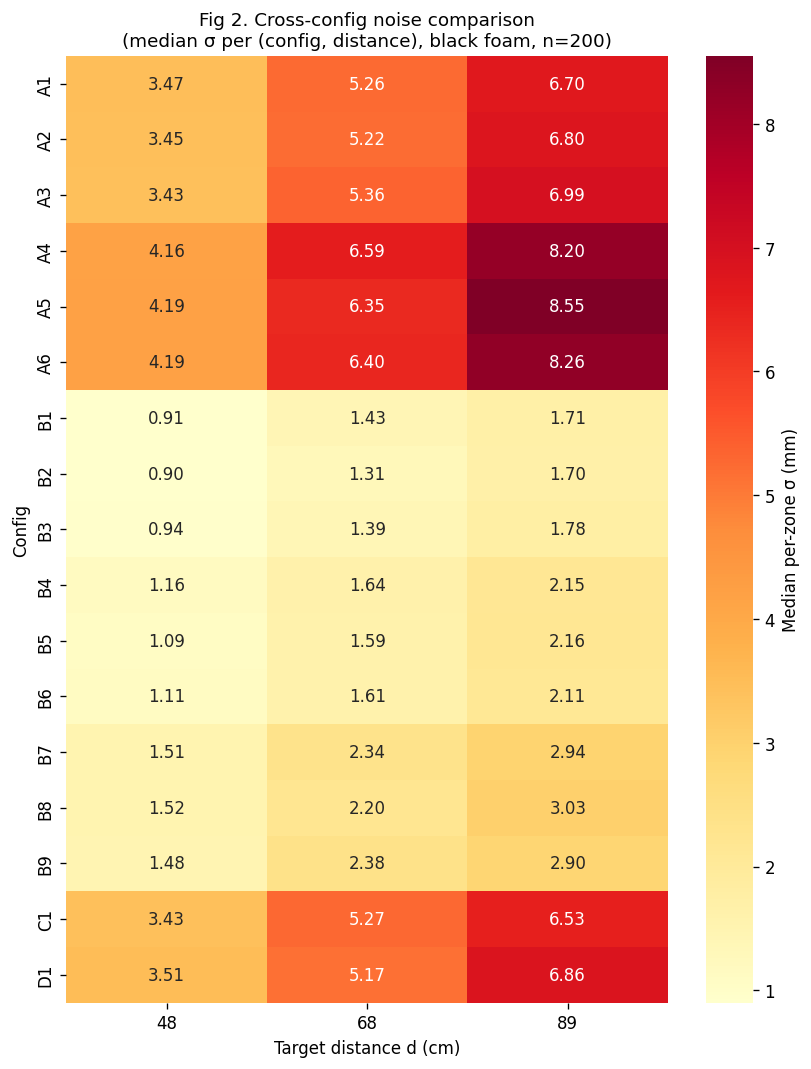
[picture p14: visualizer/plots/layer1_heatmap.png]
Fig 2 — heatmap


**What this is:** Same dataset as Fig 1, reshaped as a heatmap so I can spot patterns by row. Dark = noisier (worse), light = tighter (better).

**What I take from it:** Two clean clusters jump out — the orange 8×8 block at the top (σ = 3–8 mm) and the pale 4×4 block in the middle (σ = 0.9–3 mm). Within each block, my rows are nearly identical across the three sharpener values (0/5/20), confirming the sharpener has no measurable effect on a uniform surface. My C1 (STRONGEST target order) and D1 (strict status filter) rows match A2 (CLOSEST / lax) within noise — those two knobs only matter when there's actual scene ambiguity (multiple targets per zone, partial-quality reads), which my flat foam board doesn't provide.

#### Figure 3 — Isolated knob-impact studies

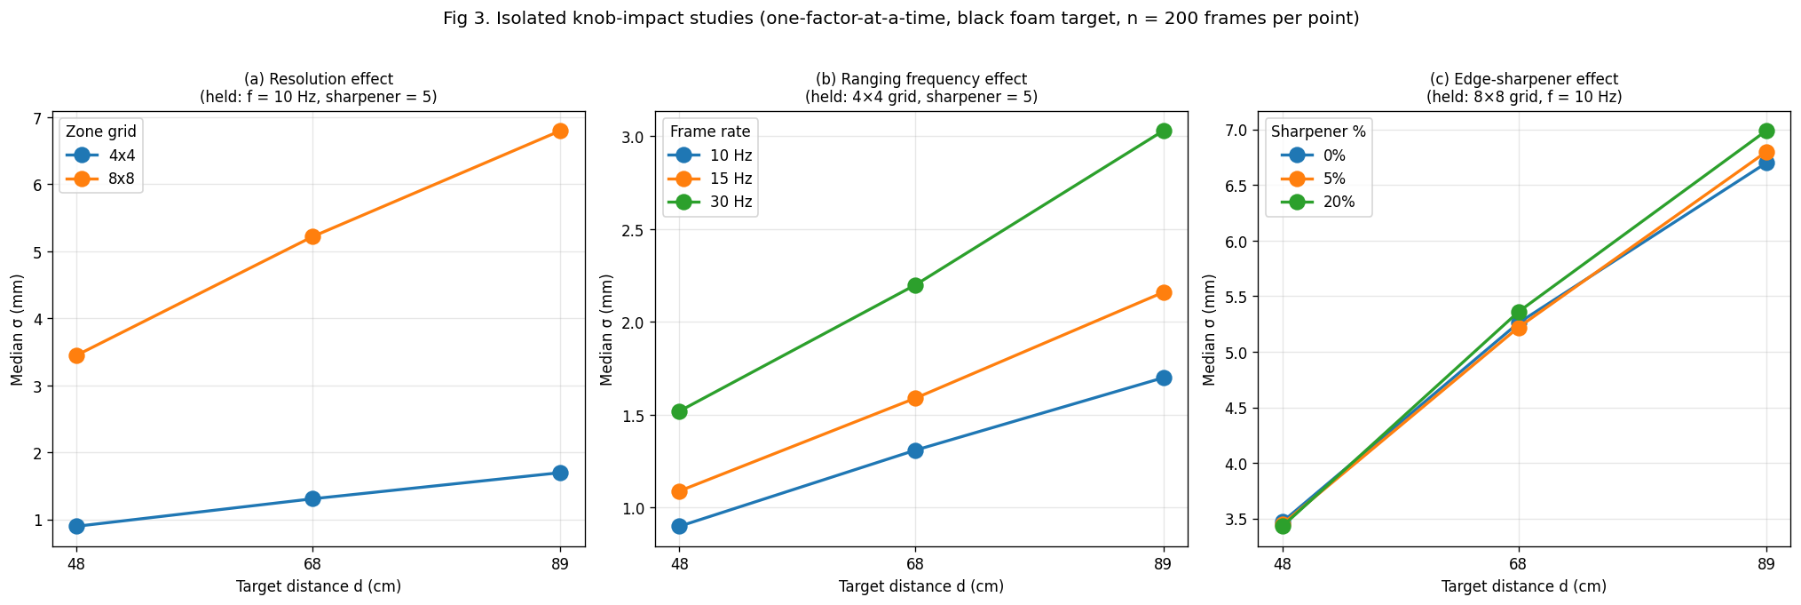
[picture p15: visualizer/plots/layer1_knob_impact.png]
Fig 3 — knob impact panels


**What this is:** Three one-factor-at-a-time studies. Each panel varies one knob with the others held fixed, so I can attribute the effect cleanly. Panel (a) = resolution; panel (b) = ranging frequency; panel (c) = edge-sharpener.

**What I take from it:**
- **(a) Resolution dominates every other knob.** 4×4 buys me ~4× tighter σ at every distance I tested. Each 4×4 zone aggregates 4× more SPADs than an 8×8 zone, AND the firmware can spend ~4× longer integrating per zone (same total budget, fewer zones). The combined effect is much larger than the naïve 2× shot-noise prediction from SPAD count alone.
- **(b) Frequency has a real noise cost.** My 10 → 15 → 30 Hz points track roughly √(freq) — exactly what I'd predict from less integration time per frame. Useful trade-off knob: I pay σ for faster reaction time.
- **(c) Sharpener is a no-op on this surface.** All three sharpener values overlap. The sharpener is a post-processing edge enhancement; on a uniform flat board with no edges to enhance there's nothing for it to do. I'd expect this to look different on doorways or furniture corners, but my static rig can't tell.

#### Figure 4 — Sensor self-calibration check

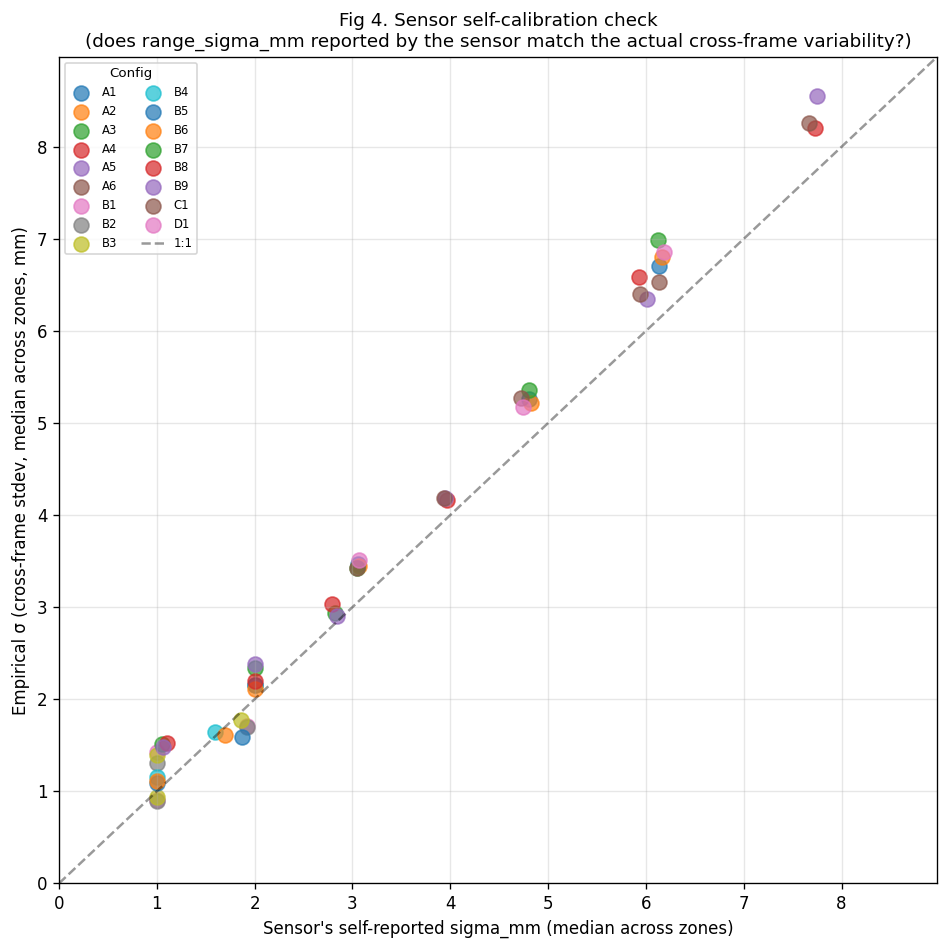
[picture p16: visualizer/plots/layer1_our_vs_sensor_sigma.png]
Fig 4 — measured vs reported sigma


**What this is:** The sensor reports its own per-reading confidence estimate (`range_sigma_mm`). This plot puts the sensor's self-reported sigma on the x-axis against my empirically-measured cross-frame stdev on the y-axis. The dashed line is 1:1 (perfect agreement).

**What I take from it:** My points hug the 1:1 line across every config. That tells me the sensor's confidence number is trustworthy and I can use it directly for downstream filtering (e.g. "ignore any zone whose reported sigma > 50 mm") without computing my own running stdev at runtime. Important for the helmet: on the ESP I won't have time to do batch statistics per frame, so being able to lean on `range_sigma_mm` from a single measurement is a big win.

#### Figure 5 — Per-zone spatial σ maps

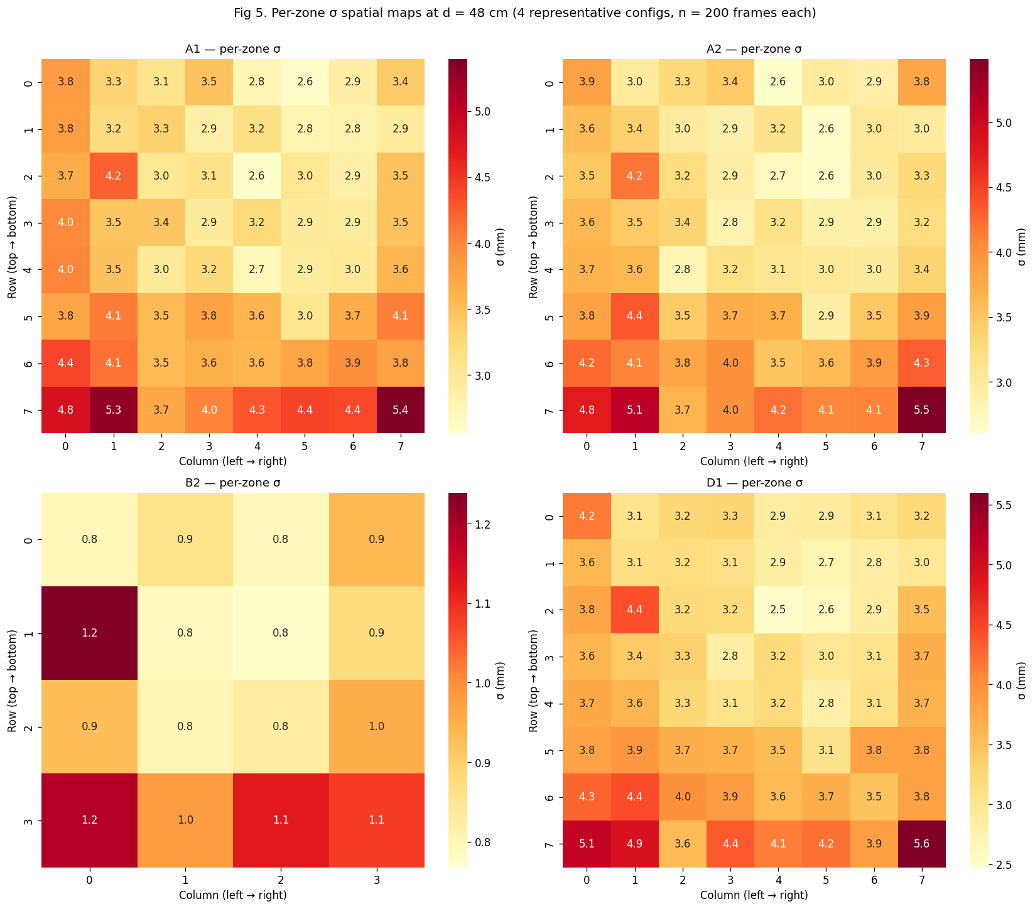
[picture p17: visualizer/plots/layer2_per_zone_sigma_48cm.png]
Fig 5a — per-zone sigma at 48cm

<p align="center"><em>at d = 48 cm</em></p>

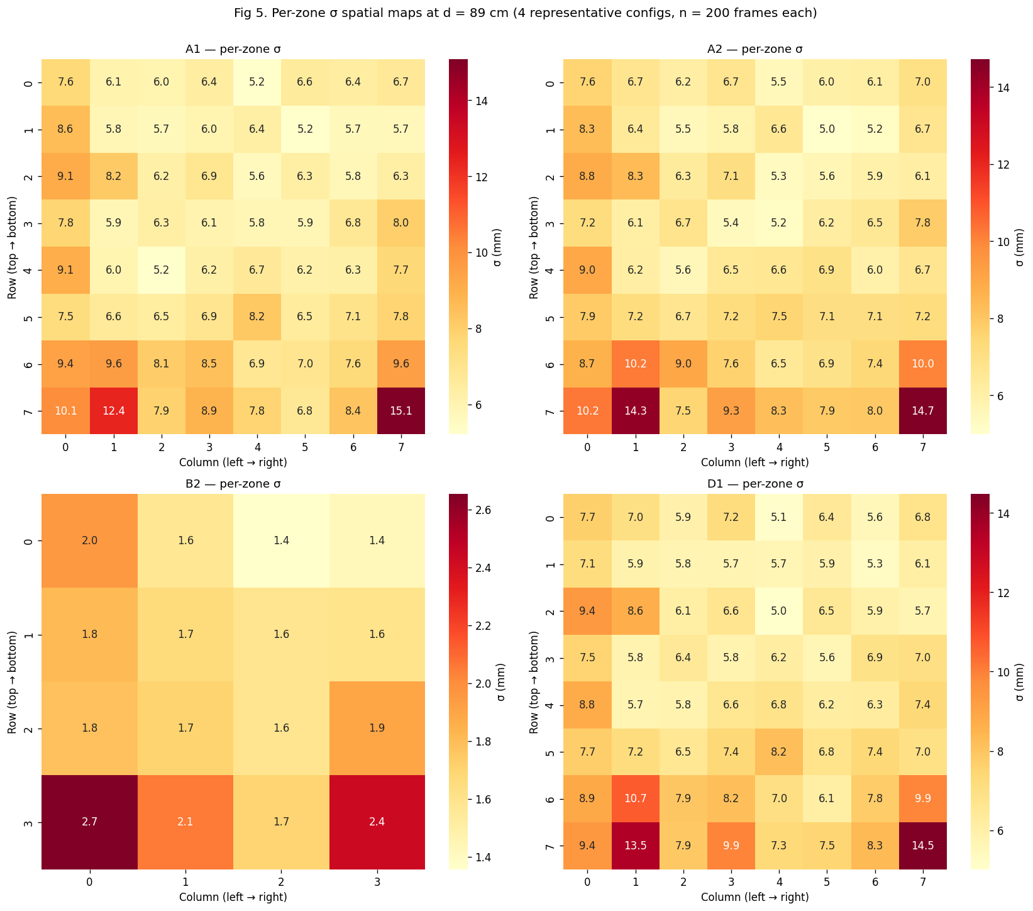
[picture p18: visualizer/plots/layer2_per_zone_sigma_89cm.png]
Fig 5b — per-zone sigma at 89cm

<p align="center"><em>at d = 89 cm</em></p>

**What this is:** Each square is the cross-frame σ for one specific zone of the array (8×8 for A1/A2/D1, 4×4 for B2). I show the same configs at two distances so I can see how the spatial pattern changes with range.

**What I take from it:** Zones aren't equal. Even on a flat uniform target, my σ varies by ~50 % across the FoV — the corners are noisier than the center because the optical return is weaker at oblique angles (cosine fall-off of the surface). For the obstacle-avoidance use case this tells me I should **weight my center zones more heavily** than the edges when fusing, or just drop the corner zones from the alert logic entirely. The 4×4 panel (top-right) is tighter at every single cell, not just on average.

#### Figure 6 — Mount-tilt diagnostic

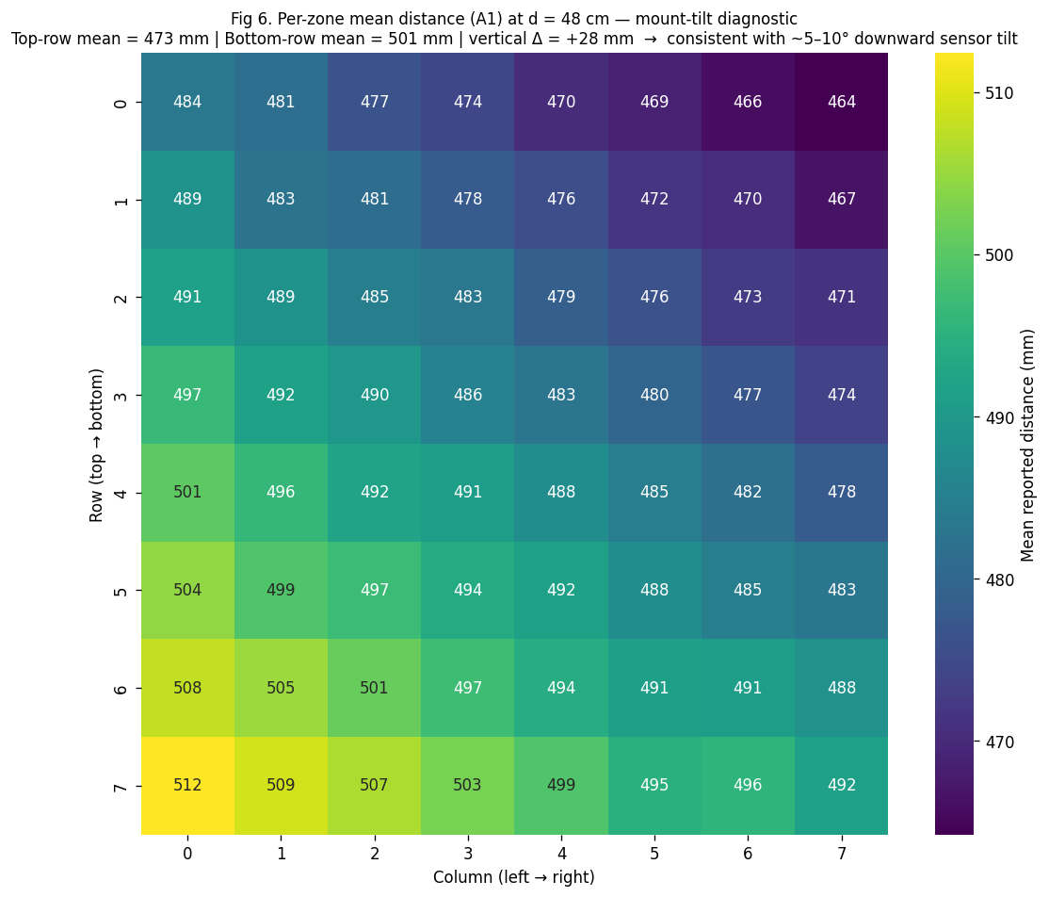
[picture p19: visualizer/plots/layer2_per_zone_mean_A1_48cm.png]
Fig 6a — per-zone mean at 48cm

<p align="center"><em>at d = 48 cm</em></p>

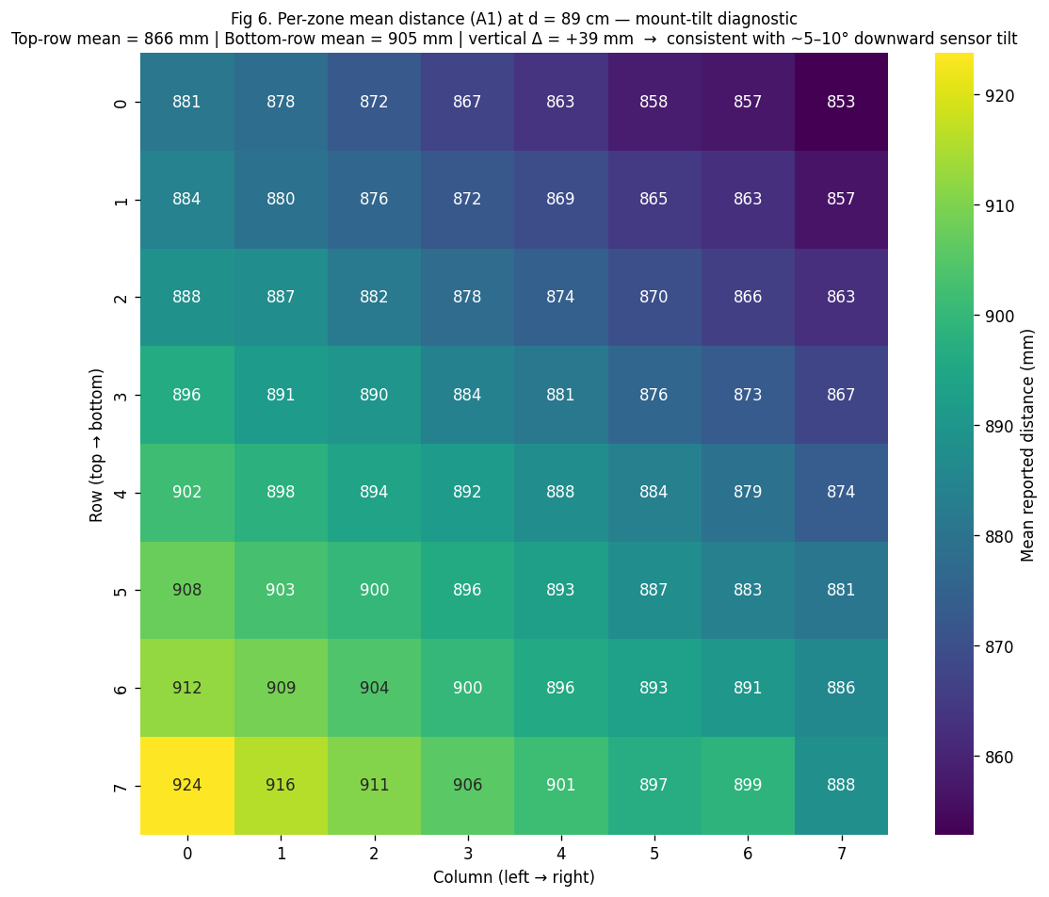
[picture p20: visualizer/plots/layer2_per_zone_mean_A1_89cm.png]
Fig 6b — per-zone mean at 89cm

<p align="center"><em>at d = 89 cm</em></p>

**What this is:** Per-zone **mean** distance over my 200 frames (vs Fig 5 which shows per-zone σ). At 48 cm the target is at ~480 mm; at 89 cm it's at ~890 mm. Color = mean reading per zone; annotations are the exact values.

**What I take from it:** The clean **top-to-bottom gradient** (~28 mm at 48 cm, ~50 mm at 89 cm) directly visualises my sensor's mount tilt. Top rows read closer than bottom rows because the sensor on my rig was angled slightly down — those upper-row zones look at the upper part of the board head-on, while the lower-row zones look at the lower part on a longer slant path. This confirms the ~5–10° downward tilt I had eyeballed at setup, and tells me that **before I can compute a meaningful "nearest object" distance I need a per-zone geometric correction** that accounts for the actual mount angle. For the helmet that compensation has to come either from a known fixed mount geometry (good enough for v1) or from a live IMU pitch reading once I add the IMU later.

### My tentative config picks (provisional — see Limitations below)

- **4×4 over 8×8** for the helmet, unless I find a use case that genuinely needs the spatial detail. 4× lower noise floor is too big to give up.
- **10 Hz** as the default frame rate — buys ~2× better σ vs 30 Hz, still fast enough to react at walking speed.
- **Skip the sharpener** until I'm working with edge-rich scenes (doorways, furniture corners). Currently a no-op on my test surfaces.
- **Keep target order on CLOSEST** — safer default for obstacle avoidance, zero cost on simple scenes. Out-of-the-box default is STRONGEST per ST UM3109 §4.9, so this is an explicit override I'm carrying.
- **Keep status filter on lax {5, 6, 9}** — I get 100 % status-5 at short range on most surfaces anyway, and the lax filter is more forgiving when surfaces get harder.
- **Apply per-zone geometric correction** before computing "nearest distance" if the sensor mount tilts more than a few degrees off the ground plane.

### Limitations of this analysis

The static foam-board sweep tells me the sensor's **physical noise floor**, but it doesn't tell me which configuration will actually be best on a moving helmet in real environments. The bottleneck in wearable use is rarely shot noise — it's:

- **Ambient sunlight** saturating the SPADs (my room had indirect daylight; outdoor noon is a different game)
- **Surfaces I didn't test:** glass, polished floors, dark fabric at oblique angles, mirrors
- **Motion noise** during head turns (none of my data is moving)
- **Geometric coverage gaps** — the things I've already noticed while wearing the helmet (missed pullup bar above sensor height, missed low obstacles near my body that read as far slant distances)
- **Edge-rich scenes** where the sharpener might actually matter (the sweep didn't include any)

So my "best-config" picks above are **provisional**. They're the right defaults to start dynamic wearable testing with, not a final decision. The next phase of this project is to wear the helmet, walk through real environments, and let those constraints reveal which knobs need re-tuning.

The full raw data behind every plot lives in [`visualizer/raw_frames/`](visualizer/raw_frames/) (51 CSVs, 200 frames × 64 or 16 zones × distance + sigma + status — nothing aggregated, nothing thrown away). To regenerate the plots from scratch: `python analyze.py` inside `visualizer/venv`.

### v9 architecture

```
              ┌────────────────────────────────────────────────┐
              │              run_sweep.ps1 (host)              │
              │  loop over 17 configs:                         │
              │   ├─ patch main.c #defines                     │
              │   ├─ idf.py build                              │
              │   ├─ curl -X POST /update  (OTA reflash)       │
              │   ├─ wait for ESP reboot + TCP-3333 alive      │
              │   └─ measure.py --frames 200 --config <label>  │
              └──────────┬─────────────────────────────────────┘
                         │  TCP 3333 (data stream)
                         ▼
┌────────────────────────────────────────────────┐
│              ESP32-S3 firmware                 │
│ ┌──────────────┐    ┌─────────────────────────┐│
│ │ ranging_task │ ─► │ tcp_write (broadcasts  )││ ── DATA:…
│ │  (sensor I²C │    │ to up to 4 clients     )││ ── SIGMA:…
│ │   @ N Hz)    │    │                        )││ ── STATUS:…
│ └──────────────┘    └─────────────────────────┘│
│ +  OTA HTTP server on port 80 (POST /update)   │
└────────────────────────────────────────────────┘
                         │  TCP 3333
              ┌──────────┼───────────────────────┐
              │          │                       │
              ▼          ▼                       ▼
       ┌──────────┐ ┌──────────────────┐ ┌────────────────────┐
       │ Live     │ │ measure.py       │ │ ... (up to 4)      │
       │ visual-  │ │ → CSV + raw     │ │                    │
       │ izer     │ │   per-frame logs│ │                    │
       └──────────┘ └──────────────────┘ └────────────────────┘
```

### Files added

- `visualizer/run_sweep.ps1` — outer loop, all 17 configs
- `visualizer/run_retry.ps1` — re-runs subset (failed configs)
- `visualizer/run_one_test.ps1` — patch + build + OTA + capture, with 3x retry
- `visualizer/analyze.py` — load CSVs, generate the 8 plots
- `visualizer/measurements.csv` — per-zone aggregates (one row per zone per run)
- `visualizer/measurements.summary.csv` — one row per run (the rank-able file)
- `visualizer/raw_frames/*.csv` — every frame's distance + sigma + status per zone
- `visualizer/plots/*.png` — analysis output
- `photos/test_rig/` — rig photos, FoV math, future-test ideas

### Lessons from v9 dev

- **OTA can leave one partition in a bad state.** ESP-IDF rotates between `ota_0` and `ota_1` on each OTA. After ~30+ cycles in a row I hit a state where one slot booted cleanly and the other hung. **My fix:** USB-flash via `idf.py -p COM10 flash` rewrites bootloader + both slots + `ota_data_initial` cleanly. Once I did that one manual recovery flash, the next dozens of OTAs worked fine.
- **`MSG_DONTWAIT` on `send()` is essential for fan-out broadcast.** Without it, a slow-reading client stalls the ranging task for every other client. Per-client failure now self-evicts the slot in my `tcp_write` loop.
- **PowerShell + UTF-8-no-BOM scripts = silent parse error.** Em-dashes (`—`) in `.ps1` files trip Windows PowerShell 5.1's parser with a misleading "missing closing brace" error pointing at the wrong line. Stuck to ASCII after I burned an hour chasing that.
- **`$ErrorActionPreference = "Stop"` makes Python tracebacks escape my retry loop.** I had to wrap the `measure.py` call in a `try`/`catch` AND momentarily set EAP to `Continue`, or one Python crash would kill the whole sweep instead of triggering the next retry attempt.
- **Sensor I²C init flakes ~20 % after a warm reboot.** Likely a power-rail dip from WiFi startup current. My firmware mitigation (start the ranging task first, give it a 2.5 s head start before WiFi comes up) helps but doesn't eliminate it. My host-side 3× retry catches the remainder.

### Refinements I added after the initial sweep (preparing for dynamic testing)

These came up immediately after the static sweep, while I was getting the sensor ready to actually wear:

- **Firmware-side mount-rotation compensation** (`MOUNT_ROTATION_DEG` in `main.c`). The sensor on my helmet sits rotated 90° from "natural" body orientation. Rather than fix it in every host script independently, I added a `rotated_zone()` helper in firmware and threaded it through all three stream functions (`DATA:` / `SIGMA:` / `STATUS:`). The chip now emits zones in body-frame regardless of how the breakout board is physically oriented on the helmet — single source of truth, every downstream consumer (visualizer, `measure.py`, future slant-compensation logic) sees correct orientation automatically. Supports 0 / 90 / 180 / 270 by changing one `#define`.
- **Visualizer frame-rate decoupling.** The old reader thread emitted a Qt signal for every frame it received from the TCP stream. If the GUI thread couldn't keep up, Qt's signal queue accumulated indefinitely — after a few thousand frames the visualizer lagged badly and eventually froze. I switched the reader to write the latest frame into a shared variable and the GUI to render via a 30 Hz `QTimer`. Older frames now get silently overwritten; no queue accumulation, no lag growth.
- **Visualizer auto-reconnect** with a backoff. The old version died on any socket timeout. The new one catches `socket.timeout` and `OSError` ("cannot read from timed out object", which the buffered file reader raises differently), closes the socket, and reconnects. This matters during the OTA cycle — every flash drops the connection, and now the visualizer comes back automatically when the ESP reboots.

---

## v10 — Wearable: helmet mount, body-frame alerts, phone-direct viewer

v9 proved what the sensor could do on a desk. v10 was about actually wearing the thing and getting it to behave like an obstacle-warning device for someone moving through real space. This iteration is much more about the *system* than the sensor — calibrating the mount, converting raw sensor readings into body-relative distances, deciding what's worth alerting on, and giving myself a way to debug the rig while walking around.

### What changed

**Firmware-side mount-rotation compensation.** The sensor PCB on my helmet sits rotated 90° from its "natural" orientation. Rather than fix that in every host script, I added a `MOUNT_ROTATION_DEG` constant (270°) and a `rotated_zone()` helper that remaps zone indices inside the firmware's stream functions. Every downstream consumer — visualizer, `measure.py`, slant-compensation logic, the new phone viewer — now sees zones in body frame automatically.

**Wall-stare tilt calibration.** I wrote `visualizer/calibrate_tilt.py`: wear the helmet, stand still facing a flat wall at a known distance, capture 200 frames, fit the sensor's actual mount pitch from the per-row mean distance pattern. The fit said **~13° pitch down** on the first iteration. After repositioning the mount I re-measured and the current value is **20° down**. The calibration also revealed a small roll component (the gradient across columns was non-zero, suggesting the sensor isn't perfectly aligned with body axes) — small enough to ignore for v1.

**Per-row slant→forward compensation.** With pitch known, each row of the rotated 8×8 grid has a known elevation angle. The firmware now precomputes a per-row cosine table at boot and converts each zone's slant distance to body-frame forward distance: `forward = slant × cos(zone_elevation + mount_pitch)`. The buzzer now alerts on **forward distance**, not slant. Fixes the failure mode I saw before: a chair 50 cm in front of my body but 50 cm tall reads a 130 cm slant distance — without this compensation the buzzer never triggers because the slant is past threshold.

**Per-row alert thresholds.** Single global threshold of 60 cm didn't work because the bottom rows' field of view exits the body-near region before an obstacle can reach 60 cm forward. By the time a chair-height obstacle is 60 cm forward of my body, it's already outside the sensor's downward cone — the firmware has no ray pointing at it. Fix: each row gets its own threshold, scaled for how soon obstacles leave its FoV.

| Row | Body region | Threshold (cm) |
|---|---|---|
| 0 | Overhead | 60 |
| 1 | Head | 60 |
| 2 | Upper head | 60 |
| 3 | Head / shoulder (optical axis area) | 60 |
| 4 | Shoulder | 70 |
| 5 | Upper chest | 80 |
| 6 | Chest | 85 |
| 7 | Belly button / waist | 90 |

Bottom rows fire while obstacles are still in view; top rows still use the tight 60 cm so overhead obstacles don't chirp the buzzer when I look around in a room with normal ceilings.

**Phone-direct web viewer.** Earlier I tried Spacedesk (mirror laptop screen to iPhone) for viewing the data while wearing the helmet. It didn't work across rooms and was laggy when it did. Switched approach entirely — the ESP itself now serves a tiny HTML viewer on `GET /`. The page polls `GET /api/status` every 200 ms for JSON containing nearest forward distance, the per-row thresholds, alert state, and the full 64-zone grid. Phone opens `http://192.168.1.228/` in Safari, sees live data, no laptop in the loop. Works anywhere on the same WiFi.

The big number is the nearest forward distance (in cm). Background colour flips green→yellow→red. Each cell in the 8×8 grid is coloured against its own row's threshold (so the bottom row goes red at a different distance than the top row). The viewer pulls the threshold table from the JSON, so when I change thresholds in firmware I don't have to edit the viewer.

**Bootloader rollback.** During wearable testing I bricked the ESP a few times — one of the OTA partitions would end up with a half-written image, the ESP would boot into it, and hang. Enabled `CONFIG_BOOTLOADER_APP_ROLLBACK_ENABLE` in `sdkconfig.defaults` and added a confirmation task that waits for WiFi + first sensor frame to succeed, then calls `esp_ota_mark_app_valid_cancel_rollback()`. If the new image fails to confirm (because the app crashed or WiFi never came up), the bootloader auto-reverts to the previous slot on the next boot. No more rescue USB-flashes for bad-boot bricks.

**OTA diagnostics.** Separately from the bricks-on-boot, I also kept seeing OTA writes drop mid-stream at the ~65 KB mark after many sequential OTAs. Couldn't reproduce reliably enough to fix the root cause yet, but I added enough instrumentation to diagnose next time it happens: verbose ESP-IDF logging (`CONFIG_LOG_DEFAULT_LEVEL_VERBOSE`), per-64-KB heap reporting inside the OTA handler, a new `GET /api/health` endpoint that returns free heap + min-free heap + uptime so I can monitor heap fragmentation over a session from the phone. My current hypothesis is heap fragmentation after long uptime, but I don't have data yet.

**Visualizer fixes.** The PyQt visualizer was accumulating Qt signal queue items when rendering couldn't keep up with the 15 Hz stream — after a few thousand frames it lagged badly and eventually froze. Decoupled the rates: reader thread writes to a shared "latest frame" variable, GUI renders at fixed 30 Hz via a `QTimer`, intermediate frames silently overwritten. Also added auto-reconnect with backoff so the visualizer survives ESP reboots during OTA cycles instead of dying.

### The hard physics finding

While testing, I confirmed something I'd suspected from the FoV math: **one head-mounted sensor cannot cover both above-head obstacles and belly-button-at-60-cm obstacles**. The numbers:

- Sensor at ~186 cm helmet height, pitched 20° down, 45° vertical FoV
- Cone reaches from 2.5° above horizontal to 42.5° below horizontal
- For an obstacle 60 cm forward of my body at belly button height (~120 cm): requires a ray at 47.7° below horizontal — outside the cone
- To cover from "slightly above head" down to "belly button at 60 cm" requires ~61° of vertical FoV; the sensor has 45°

Three ways out:
1. **Bump pitch to 25–30°** — catches belly button, loses everything above horizontal
2. **Mount sensor lower (chest level)** — catches belly button as near-horizontal, loses overhead
3. **Add a second sensor aimed down** — keeps the head-mount for overhead, dedicated second sensor for lower body. This is the real fix and it's on the todo list.

I'm running v10 with pitch 20° (keeps top-of-FoV overhead detection while extending lower coverage to chest), and accepting the belly-button-and-below blind spot at close range until I add the second sensor. The per-row thresholds make the most of what the sensor CAN see.

### v10 architecture

```
                ┌─────────────────────────────────────────┐
                │           ESP32-S3 firmware             │
                │                                         │
   ┌────────┐   │  ┌──────────────┐    ┌──────────────┐   │
   │ VL53L8 │──►│  │ ranging_task │    │ HTTP server  │   │
   │  CX    │I²C│  │              │    │  port 80     │   │
   └────────┘   │  │ -rotation    │    │              │   │
                │  │ -slant comp  │    │ GET /        │──►── HTML viewer
                │  │ -per-row     │    │ GET /api/    │──►── JSON status
                │  │  threshold   │    │  status      │      (nearest, alert,
                │  │              │    │ GET /api/    │       grid, thresholds)
                │  │ → g_alert    │    │  health      │──►── JSON diagnostics
                │  │ → g_nearest  │    │ POST /update │◄──── OTA reflash
                │  │ → g_grid     │    │              │
                │  └──────┬───────┘    └──────────────┘   │
                │         │                               │
                │         ▼                               │
                │  ┌──────────────┐    ┌──────────────┐   │
                │  │ buzzer_task  │    │ tcp_server   │   │
                │  │              │    │  port 3333   │──►── raw DATA/SIGMA/
                │  │ beep if      │    │ (4 clients,  │     STATUS lines
                │  │  any zone <  │    │  broadcast)  │     (for measure.py
                │  │  row thresh  │    │              │      and analysis)
                │  └──────────────┘    └──────────────┘   │
                └─────────────────────────────────────────┘
                          │                  │
                          ▼                  ▼
                     active buzzer      iPhone Safari or
                     on GPIO 6          laptop visualizer
```

### Lessons from v10 dev

- **The slant→forward conversion is meaningless if you ignore the FoV.** I spent time chasing why "body-level obstacles aren't detected" when the math was already doing what I asked. The math was correct — the obstacles just weren't in the sensor's cone. Always sanity-check whether the sensor can even *see* a thing before debugging why it doesn't *react* to it.
- **Mirror-via-screen-share doesn't scale to "walk around with a phone".** Spacedesk worked great when I was sitting next to my laptop, fell over when I walked into another room. The fix wasn't a better mirror tool; it was a different architecture (ESP serves the viewer directly).
- **Per-row thresholds are a clean way to encode "what each row is looking at".** Cleaner than a single global threshold + heuristics. Easier to tune empirically by walking around with the viewer and watching which cells fire.
- **Bootloader rollback is a one-config-line fix worth doing on any OTA-equipped device.** I should have enabled it on day one of v7. Cost: zero. Benefit: no more bricked partitions from interrupted/bad OTA writes.
- **Heap monitoring matters once you have multiple long-running tasks.** `/api/health` is two lines of code and gives me forever-running insight into whether memory is leaking or fragmenting.

### Files added/changed in v10

- `main/main.c` — rotation helper, slant-cos table, per-row thresholds, `g_alert_active` flag, OTA rollback confirm task, viewer HTML embedded, `/api/status` + `/api/health` JSON endpoints, OTA diagnostic logging
- `sdkconfig.defaults` — `CONFIG_BOOTLOADER_APP_ROLLBACK_ENABLE=y`, `CONFIG_LOG_DEFAULT_LEVEL_VERBOSE=y`
- `main/CMakeLists.txt` — added `esp_timer` requirement
- `visualizer/calibrate_tilt.py` — wall-stare tilt-angle fitter
- `visualizer/visualizer_simple.py` — frame-rate decoupling, auto-reconnect with backoff, adaptive 8×8/4×4 zone count
- `visualizer/raw_frames/wall-tilt-calib-h185cm-d81cm_*.csv` — calibration capture
- `photos/test_rig/test_rig_notes.md` — updated with helmet-mount height
- `todo.md` — living list of where this project is going

---

## v11 — Directional haptic feedback (3-motor ring)

v10's buzzer encoded *distance* via beep rate but not *direction* — a chirp told me something was close, but not whether it was to my left, ahead, or right. v11 adds three ERM coin motors driven from the ESP, mapped to the FoV's left / center / right columns, so the alert is now two-dimensional: the buzzer says "obstacle, close" and the motor against my skin says "on your left."

### What changed

**Three vibration motors on GPIOs 7 / 15 / 16.** Each motor is switched by a low-side 2N3904 NPN BJT (1 kΩ base resistor, motor sits between collector and 3V3, emitter to GND). All three share LEDC timer 1 at 1 kHz across channels 1–3 (the buzzer keeps timer 0 / channel 0 — independent), so PWM duty cycle controls intensity per-motor with no cross-talk. Physical mapping (verified 2026-05-28 by single-pin pulse test): **GPIO 7 = center / forehead**, **GPIO 15 = right temple**, **GPIO 16 = left temple**.

**`HAPTIC_TEST` build flag in `main.c`.** Setting `#define HAPTIC_TEST 1` makes `app_main` skip the sensor ranging task and run `haptic_test_task` instead — full-on for 1.5 s on motor A, then ramp; same for B then C; then all three together. WiFi + the OTA HTTP server still come up, so I can OTA back to normal firmware without touching USB. This is the workflow that proved out all three motors over the air in a single afternoon (2026-05-28).

**Boot-time safety GPIO config.** Before anything else in `app_main` — even before NVS or WiFi — the three motor GPIOs are explicitly forced to OUTPUT-LOW with a pulldown enabled. Runs regardless of `HAPTIC_TEST`. This belt-and-suspenders step exists because of a real failure I hit during bring-up: a motor wired directly between 3V3 and ground (bypassing the transistor) was running continuously, generating broadband brush-arc noise that coupled onto the shared 3V3 rail AND radiated into the nearby I²C pull-up wires, corrupting the VL53L8CX's ~80 KB ULD firmware upload at sensor init. Fixing the wiring restored the sensor; the safety config ensures even a stuck-on transistor or a flaky reboot can't leave a motor running silently and overheating.

### Bring-up sequence I followed

Documented in [`docs/haptics-bringup.md`](docs/haptics-bringup.md), but the short version:

1. **Motor sanity** — motor leads briefly to 3V3 + GND. Confirms motor is alive and is NOT a piezo (piezo reads open-circuit; this read 70 Ω → real coil → needs flyback diode for clean switching).
2. **Driver build** — 2N3904 + 1 kΩ base resistor. Verified with multimeter diode mode (B→E and B→C both ~0.7 V) to confirm the pinout (E-B-C left-to-right, flat face toward me).
3. **One motor on GPIO 7** with `HAPTIC_TEST = 1`. OTA-flashed. Felt smooth ramp 0→100 %. (2026-05-26.)
4. **Scaled to three motors** on GPIO 7 / 15 / 16. Per-motor phase verified each one fires on cue; all-three-together at full duty draws ~130 mA on the shared 3V3 rail without browning out the regulator or any visible sensor disturbance. (2026-05-28.)
5. **Caps + diodes intentionally skipped for bench**. The 1N5819 Schottky kit is in the mail; 33 µF + 22 µF caps are on hand but not soldered. Recommended for the final worn-perfboard build, not required for the dev board.

### Why directional haptics matter for this helmet

For a visually-impaired user, "something is close" without "where" forces them to stop and sweep their head to localise — exactly the failure mode Ghaffari et al. 2025 hit with single-buzzer alerts. With three motors at left temple / forehead / right temple the alert encodes left / centre / right directly into skin, which (per their wrist-haptic study) the brain localises laterally with near-100 % accuracy in well-separated mounts. The centre (forehead) motor stays useful as a "straight ahead" cue even when the user is turning, because head-relative direction is what they actually need to steer around.

Comfort caveat: the same Ghaffari paper switched from head to wrist haptics because pilot users found head-mounted ERMs uncomfortable for sustained wear. Worth pressure-testing the helmet ring on long sessions before committing to the design.

### Directional drive (column → motor) — live in sensor mode

`ranging_task` drives all three motors every frame from the live depth grid:

- **Column → motor:** body-frame col 0 → LEFT (GPIO 16), cols 1–2 → CENTER (GPIO 7), col 3 → RIGHT (GPIO 15). Generalizes to 8×8 (outer quarter of columns → side motors).
- **Per-motor urgency:** each motor tracks the *most-urgent* obstacle (lowest forward/threshold ratio) in its column region, same integer cross-product math as the buzzer.
- **Squared duty curve with a floor:** `duty = MIN + (MAX − MIN) × (1 − ratio)²`. The squared shape concentrates intensity near point-blank (Stevens-law-supported for alerting); the `HAPTIC_DUTY_MIN` floor (130) jumps an alerting motor straight to "just-felt" the instant the buzzer fires — without it, the ERM dead zone left the motor silent until ~20 cm.
- **Dominance weighting:** when ≥2 motors fire, the strongest keeps full duty and the others have only their *above-floor* portion scaled to 70 %, so they stay felt but clearly secondary (mitigates the multi-motor comprehension drop documented in Zegarra Flores 2022).

Full design + primary sources: [`docs/research-sources/directional-haptics-mapping.md`](docs/research-sources/directional-haptics-mapping.md).

### Configuration knobs

| Define | Default | Notes |
|---|---|---|
| `HAPTIC_TEST` | `0` | `1` runs the standalone 3-motor test ramp instead of the sensor pipeline. WiFi + OTA stay up either way. |
| `HAPTIC_ID_MODE` | `0` | When `HAPTIC_TEST=1`, `1` pulses only `HAPTIC_ID_GPIO` for physical-motor identification. |
| `HAPTIC_DIRECTIONAL` | `1` | Directional column→motor drive in sensor mode. `0` = buzzer-only (motors stay off) without rewiring. |
| `HAPTIC_DUTY_MIN` | `130` | ERM dead-zone floor (≈51 % of 255). An alerting motor jumps to this duty immediately; the curve ramps it to `MAX` at point-blank. Raise if weak at threshold. |
| `HAPTIC_DOMINANCE_NUM` / `_DEN` | `7` / `10` | Above-floor scale applied to non-dominant motors when ≥2 fire. |
| `HAPTIC_GPIO_CENTER` / `_RIGHT` / `_LEFT` | `7` / `15` / `16` | Verified physical mapping. Move to other free GPIOs only — avoid strapping pins 0, 3, 45, 46 on ESP32-S3. |

### Wiring (one per motor)

```
                    +3V3
                     │
                     ├──────────────┐
                   [motor]    [1N5819 Schottky]   ← optional for bench,
                     │       (cathode → +3V3)        recommended for final
                     ├──────────────┘
                     │
               Collector (pin 3, right)
                     │
   GPIO ──[1 kΩ]── Base (pin 2, middle)
                     │
               Emitter (pin 1, left)
                     │
                    GND  (shared with ESP32 GND)
```

### Lessons from v11 dev

- **Brushed DC motor noise can wreck I²C sensor init.** Brush arcing emits broadband RF that couples both conductively (shared 3V3 rail) and inductively (nearby pull-up wires). A continuously-running motor next to the sensor's I²C bus corrupted enough bits in the 80 KB ULD firmware upload that the sensor reported `is_alive = false` 100 % of the time. The motor doesn't even need to be PWM'd — DC-on is enough. Fix at the system level: cap the motor for noise (100 nF ceramic across motor terminals), bulk cap the rail (100 µF), make sure the transistor is actually in the path so the motor isn't running unless commanded.
- **A safety GPIO config at boot is cheap insurance.** Even with the test flag off, force the motor pins to a known-LOW state at the start of `app_main` before anything can configure them otherwise. Costs four lines of code per pin and prevents the worst-case "GPIO floats high on warm reboot → transistor partly conducts → motor runs forever" failure mode.
- **The `frames` field in `/api/health` is currently `g_latest_grid_side`, not an actual frame counter.** Misled me once during bring-up — saw `frames: 4` and thought the sensor had only produced 4 frames; really it meant "4×4 grid is active and streaming." Open TODO to make it a real counter; in the meantime the comment in `main.c:742` calls it out.
- **OTA-flashable test mode beats USB-flash test mode.** The `HAPTIC_TEST` flag pattern lets me iterate on motor behaviour without ever pulling the helmet off the desk for a cable swap, and without losing the sensor firmware. Same flag-and-flag-back workflow would suit any future actuator bring-up (speaker, LED ring, second buzzer).
- **A proportional curve needs a floor on a real motor.** The squared urgency curve looked right on paper but felt broken in the hand: the buzzer alerted at the threshold distance while the motor stayed dead until ~20 cm, then slammed to full. ERM coin motors simply don't spin below ~50 % duty, so the bottom half of any 0→max curve is wasted. The fix is to map the alert band onto `[MIN..MAX]`, not `[0..MAX]` — the motor is felt the moment the alert fires and the curve shapes intensity above that. This is the same "just-noticeable floor" Ghaffari 2025 uses.
- **Driving motors during normal operation reintroduces the noise risk.** Bench-testing motors in a dedicated mode was clean, but once `ranging_task` drives them continuously during alerts, a sustained point-blank obstacle pins motors at high duty and the brush noise can wedge the HTTP server on the un-decoupled bench rig. The motor caps + rail bulk cap (deferred as "optional for bench") become genuinely necessary for the worn build.

### Files added/changed in v11

- `main/main.c` — `HAPTIC_TEST` / `HAPTIC_ID_MODE` flags, verified `HAPTIC_GPIO_CENTER/RIGHT/LEFT` mapping, `haptic_test_task`, safety GPIO config at top of `app_main`; **directional drive**: LEDC infra hoisted out of `#if HAPTIC_TEST`, `haptic_motors_init()`, `haptic_motor_for_col()`, `haptic_apply()` (squared curve + `HAPTIC_DUTY_MIN` floor + dominance weighting), per-motor urgency tracking in `ranging_task`
- `docs/haptics-bringup.md` — full bring-up log: parts list, transistor pinout, driver schematic, test sequence, OTA workflow, results log, directional-drive implementation + dead-zone fix
- `docs/research-sources/directional-haptics-mapping.md` — cited research behind the mapping/curve/dominance decisions

---

## What's next (queued)

After v11 the helmet is wearable with two-dimensional alerts (distance + direction) — the buzzer encodes urgency, the three motors encode direction, and both fire together. Next steps are walk-testing, filling in the bottom 1/3 of body coverage, and graduating from a prototype to something I'd trust.

1. **Walk-test + tune the directional haptics.** The column→motor drive is implemented and bench-confirmed. Remaining is real-world tuning: dial in `HAPTIC_DUTY_MIN` for the actual motors, confirm direction holds while moving, and watch the one open stability item — the HTTP server wedged once when motors ran sustained at point-blank on the un-decoupled bench rig. Mitigations on deck: motor-terminal 100 nF + rail 100 µF caps (mailed), optional duty cap, optional HTTP watchdog.
2. **Solder the perfboard rim** when the 1N5819 Schottky diodes arrive — three transistors, three 1 kΩ resistors, three flyback diodes, one 100 µF bulk cap across the 3V3 rail, JST connectors out to the motors so the helmet can be removed without de-soldering.
3. **Second VL53L8CX aimed downward** — fixes the belly-button-and-below blind spot. SPI bus (cleaner than I²C for two sensors — no address conflict). Independent calibration, independent per-row thresholds, fused into a single body-frame alert.
4. **Multi-target per zone** (`VL53L8CX_NB_TARGET_PER_ZONE = 2`) — helps thin obstacles in open doorways (pullup bar with open space behind). Per ST UM3109 §4.10, this only resolves targets separated by ≥ 600 mm — so it won't help bars with a wall right behind them, but doorways usually have several metres of room beyond.
5. **Bird's-eye-view mode for the phone viewer** — top-down body-centered radar display instead of the sensor-grid layout. Becomes more useful once the second sensor is in (one fused view of all obstacles around me, not two separate per-sensor grids).
6. **IMU on the helmet** — gravity-anchored pitch/roll so the slant→forward correction adapts when I look up/down instead of assuming level head. Cheaper interim path: iPhone IMU streamed over WiFi UDP (Phyphox app).
7. **Phase 2 — USB camera + CV** — classify what the ToF is detecting (person vs wall vs glass) so the alert pattern can encode object type, not just distance.

Living list of all open work, hardware notes, and recurring pitfalls is in [`todo.md`](todo.md).

Full research synthesis behind the current parameter picks — including a re-analysis of my v9 data through a wearable-latency lens, plus ST documentation deep-dive, academic literature review, and commercial-device market survey — is in [`docs/research-optimal-config.md`](docs/research-optimal-config.md). Headline finding: **no peer-reviewed work exists on a head-mounted VL53L8CX ETA for the visually impaired**, so several of the open questions on the helmet are genuinely unstudied and the project will generate new data along the way.

---

## A note on process

This project was as much a deliberate experiment in working with AI tools as it was a hardware project. Every design decision — the choice of EMA α, the Kabsch derivation, the six-second cap on the world-frame memory, the validity gates on the pose estimator — was something I worked through with Claude as a thinking partner. The aim wasn't to have an AI build this for me; it was to see how far I could push a real, end-to-end embedded project by integrating an AI into the loop the way an engineer integrates any other tool — and to be exposed to a stack of topics I'd otherwise only have read about in passing.

What this gave me exposure to, more than mastery of:

- The vocabulary and shape of an embedded firmware project — ESP-IDF, I²C bus configuration, ULD firmware uploads, component-registry dependencies, sdkconfig knobs.
- Why GPU-accelerated rendering and a threaded serial reader matter for an interactive app, even when the underlying maths could in principle run on the GUI thread.
- The general form of rigid-registration / Procrustes-style problems — what they're solving and where the small-motion correspondence assumption breaks — without pretending I could derive the SVD step from memory.
- The distinction between sensor-physics limits (yaw unobservability from a flat-floor depth map) and algorithm choices, and why an IMU is the standard fix for the former.
- The discipline of writing a limitations section that names root causes rather than handwaves.

The deeper maths and systems detail I'd still need to study to claim real fluency in. What I do have is enough familiarity with each topic to read the right next paper or datasheet section, recognise when something doesn't add up, and direct the next iteration of this project once the IMU arrives.

The full [`PROGRESS.md`](PROGRESS.md) captures the process as it actually happened — every wiring mistake, every wrong field name in a struct, every I²C timeout default that bit me. AI accelerated the path through dead ends; the choices, the trade-offs, and the willingness to throw out two complete visualiser rewrites are mine.

---

## References

- [ST VL53L8CX product page](https://www.st.com/en/imaging-and-photonics-solutions/vl53l8cx.html) — datasheet, 65° diagonal / 45°-per-axis FoV, 1–15 Hz at 8×8.
- [RJRP44/VL53L8CX-Library](https://github.com/RJRP44/VL53L8CX-Library) — the ESP-IDF wrapper this project uses ([component registry](https://components.espressif.com/components/rjrp44/vl53l8cx)).
- [ESP-IDF programming guide](https://docs.espressif.com/projects/esp-idf/en/latest/) — required v5.0+.

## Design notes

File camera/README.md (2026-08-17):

# Camera folder — what everything is and where

**This folder:** `C:\esp-projects\vl53l8cx_esp32\camera\`

Open a terminal there:
```
cd C:\esp-projects\vl53l8cx_esp32
```
Every command below is run from that folder (`vl53l8cx_esp32`, not `camera`).

---

## THE STAGE MAP — one numbering, replaces everything earlier

I previously used two conflicting schemes ("Stage 1" and "Step 3" for the same thing). **This is the only one now.**

| # | Stage | What it produces | Status |
|---|---|---|---|
| **0** | Camera alive | A picture on screen | ✅ **DONE** |
| **1** | Focus + lock the lens | A lens that can never shift | 🔵 in progress |
| **2** | Calibrate the lens (*intrinsics*) | **K** and **D** | ⬜ next (morning) |
| **3** | Align ToF to camera (*extrinsics*) | **[R\|t]** | ⬜ |
| **4** | Project + overlay | **FUSION WORKING** — depth painted on video | ⬜ |
| **5** | Detection-gating | "person, 1.8 m, left" → haptics | ⬜ later |
| **6** | Mono-depth | Dense metric depth across the full 140° | ⬜ later |

**Stage 4 is the goal you asked for.** 5 and 6 are upgrades on top of it.

Every term in bold is defined in **`GLOSSARY.md`** (same folder).

---

## Files, with full paths

### Read these
| File | What it's for |
|---|---|
| `C:\esp-projects\vl53l8cx_esp32\camera\README.md` | This file — the index |
| `C:\esp-projects\vl53l8cx_esp32\camera\GLOSSARY.md` | **Every term explained, plus why each stage exists** |
| `C:\esp-projects\vl53l8cx_esp32\camera\CALIBRATION-RUNBOOK.md` | **Stage 2 step-by-step — follow this in the morning** |
| `C:\esp-projects\vl53l8cx_esp32\docs\fusion-executive-summary.md` | The whole plan, one page |
| `C:\esp-projects\vl53l8cx_esp32\docs\datasheets\camera\HBV-1716WA-VERIFIED-SPECS.md` | Hardware facts, marked official vs inferred |

### Print this
| File | What it's for |
|---|---|
| `C:\esp-projects\vl53l8cx_esp32\camera\checkerboard_8x11_20mm.pdf` | **The calibration target. Print at 100%.** |

### Run these
| Command (from `C:\esp-projects\vl53l8cx_esp32`) | Stage | What it does |
|---|---|---|
| `python camera\camera_focus.py 1` | 1 | Live view + 1:1 magnifier for focusing. **Judge with your eyes on the inset.** |
| `python camera\capture_calib.py` | 2 | Collects checkerboard photos, tracks coverage |
| `python camera\calibrate_fisheye.py` | 2 | Fits the lens model → **K**, **D** |
| `python camera\make_checkerboard.py` | — | Regenerates the PDF (already done, only if you change square size) |
| `python camera\camera_live.py 1` | — | Plain live view, `m` cycles modes |
| `python camera\camera_check.py` | — | Probes which camera index is which |

The `1` after `camera_focus.py` / `camera_live.py` is the **camera index** — your HBV is index 1, your laptop's built-in webcam is index 0.

### Produced by the scripts (they don't exist yet)
| File | Made by | Contains |
|---|---|---|
| `camera\calib_shots\calib_000.png` … | `capture_calib.py` | Your checkerboard photos |
| `camera\calibration_720p.npz` | `calibrate_fisheye.py` | **K and D — the actual deliverable** |
| `camera\calibration_720p.txt` | `calibrate_fisheye.py` | Readable report + **measured field of view** |
| `camera\undistort_preview.jpg` | `calibrate_fisheye.py` | Before/after picture to eyeball |
| `camera\snapshots\` | focus/live tools | Any snapshots you save with `s` |

---

## If something breaks

**"Could not open camera index 1"** — something else is holding the camera. Close other camera apps, or:
```
Get-Process python,ffmpeg -ErrorAction SilentlyContinue | Stop-Process -Force
```

**Camera vanished entirely** — unplug, wait, replug. Check it's back:
```
Get-PnpDevice -Class Camera | Where-Object { $_.InstanceId -like "*VID_0AC8*" }
```
`Present : True` = it's there. (Drop-outs during bring-up turned out to be manual unplugs.)

**Module too hot to hold a finger on** — unplug and let it cool. Above ~50 °C the sensor leaves its stable-image range (OV2710 datasheet, Table 8-2).

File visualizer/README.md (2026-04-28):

<h1 align="center">VL53L8CX Live 3D Point Cloud Visualiser</h1>

<p align="center">
  <em>PyQtGraph + OpenGL renderer for the ESP32's <code>DATA:</code> stream — animated ToF rays, side colour-bar, 6-DOF Kabsch pose estimation, and a world-frame point memory that wraps around the sensor as it pans.</em>
</p>

---

<p align="center">
  <video src="progress_demo_v6.mp4"
         controls muted autoplay loop playsinline width="820">
  </video>
</p>
<p align="center"><em>v6 — accumulated past observations slide off to the side as the sensor rotates; the cone effectively wraps around. Trail behind the sensor fades from invisible at the tail to bright yellow at the head.</em></p>

---

## What you're looking at

| Element | What it is |
|---|---|
| **64 bright dots in a cone** | Live measurements, one per zone, coloured by distance (viridis: purple = close, yellow = far). |
| **Animated coloured beams from the sensor** | One ToF ray per zone, faded from the lens out to its endpoint, in the same hue as the point. They pulse with the live data — physically what a multizone ToF sensor is doing. |
| **Faded surrounding cloud** | Past observations in **world frame**, transformed back into the current sensor frame each tick and faded by age (~6 s memory). As you rotate, they slide off to the side instead of staying glued to the front. |
| **Yellow line behind the sensor** | Estimated 6-DOF trajectory of the sensor's origin (last ~5 s), per-vertex alpha-faded so old segments disappear. |
| **Sensor body + lens ring at origin** | Flat dark rectangle modelling the SATEL-VL53L8CX face, with a bright lens circle and "VL53L8CX" label. |
| **Pale frustum** | The sensor's actual 45° × 45° field of view (per ST datasheet — 65° diagonal). |
| **Side colour bar** | Distance scale in mm. |
| **Status bar** | Live frame count, valid-zones / 64, mean valid distance, cumulative pose translation + rotation, and the per-frame rejection count. |

---

## Quick start

```bash
cd visualizer
python -m venv venv
venv\Scripts\activate           # Windows  (Linux/macOS: source venv/bin/activate)
pip install -r requirements.txt

python visualizer.py --port COM12
```

> Make sure `idf.py monitor` is **closed** before starting — only one program can hold the COM port at a time.

| Flag | Default | Description |
|---|---|---|
| `--port` | `COM12` | Serial port the ESP32 is on |
| `--baud` | `115200` | Matches the ESP-IDF console default |
| `--max-mm` | `4000` | Z-axis range + colour-scale max (mm) |

**Hotkey:** press **`R`** in the visualiser window to reset the cumulative pose and clear the trail + accumulated cloud.

---

## How it works

### 1. Serial protocol
The ESP32 streams one compact line per frame:
```
DATA:820,815,801,790,...,(64 values total)
```
Invalid zones are clamped to `MAX_DISTANCE_MM` (= 4000 mm) on the firmware side so the host always gets exactly 64 values. The visualiser detects the clamp and renders those zones with `α = 0`, hiding them.

### 2. Threaded pipeline
Serial reads run in a dedicated `QThread`; new frames are delivered to the GUI via a Qt signal. Each cycle drains everything currently buffered and keeps only the **newest** valid `DATA:` line — this kills the "rendering one frame stale" failure mode of the original implementation.

### 3. Geometric projection
The VL53L8CX is **65° diagonal / 45° per axis**. Each of 8 zones along an axis subtends `45° ÷ 8 = 5.625°`. A unit direction vector is precomputed for every zone:

```text
h_angle = (col − 3.5) × 5.625°       v_angle = (row − 3.5) × 5.625°
x =  sin(h_angle)
y = −sin(v_angle)                     (row 0 is the top of the sensor view)
z =  cos(h_angle) × cos(v_angle)      (sensor boresight = +Z)
```

Multiplying each unit vector by its zone's measured distance gives the 3D point.

### 4. EMA smoothing (α = 0.6)
Raw zones jitter ±10–30 mm frame-to-frame on a static scene. Per-zone exponential moving average:

```python
smoothed[v] = 0.6 * new[v] + 0.4 * smoothed[v]
```

α = 0.6 settles to 95 % of a step in `−ln(0.05) ÷ −ln(1 − 0.6) ≈ 3` samples — about 200 ms at 15 Hz. Tunable in `visualizer.py`.

### 5. 6-DOF relative pose (Kabsch / Procrustes)

Closed-form rigid registration on consecutive 64-point clouds. Given paired sets P (frame k−1) and Q (frame k):

```text
1.  Pc, Qc      = P − mean(P), Q − mean(Q)
2.  H           = Pc.T @ Qc
3.  U, S, Vt    = svd(H)
4.  d           = sign(det(Vt.T @ U.T))         # reflection guard
5.  R           = Vt.T @ diag(1, 1, d) @ U.T
6.  t           = mean(Q) − R @ mean(P)
```

The fitted (R, t) maps a world point's old-frame coords to its new-frame coords. The **sensor's** per-frame motion is the inverse: `δR = R.T`, `δt = −R.T @ t`. World-frame cumulative pose composes as `T_world(k) = T_world(k-1) · δ`.

We rely on **same-zone correspondence under the small-motion assumption** — at 15 Hz (~67 ms per frame) zone *i* in two consecutive frames still observes approximately the same world point. Wrong correspondence (fast motion) shows up as huge fitted Δt or ΔR; the estimator gates on `≤ 300 mm` and `≤ 20°` per frame and breaks the chain instead of corrupting cumulative state.

### 6. World-frame point memory (v6)

Each frame, valid sensor-frame points are transformed via `world_p = R_world · sensor_p + t_world` and pushed into a rolling 6-second deque. For rendering, every entry is transformed *back* into the current sensor frame and given an alpha proportional to its age (newest = ~0.35, oldest = 0). The visual effect: as the sensor pans, old observations stay fixed in space and slide around.

---

## Honest limits

- 64 points × ±10–30 mm noise is sparse and noisy for ICP-style registration. Expect drift, especially in **yaw** (rotation around gravity is unobservable from a flat-floor depth map — no algorithm can recover it from depth alone).
- 0/64 valid zones (covered sensor, loose connection) → estimator pauses cleanly.
- The 6-second memory cap keeps drift damage local. With an IMU added later, the same code becomes a usable sparse 3D map.

For full development context — every visualiser iteration, every fix, the evidence behind each decision — see [`../PROGRESS.md`](../PROGRESS.md).

---

## Hardware this runs on

| Component | Detail |
|---|---|
| Sensor | STMicroelectronics SATEL-VL53L8CX (8×8, 65° diagonal, 1–15 Hz) |
| Microcontroller | ESP32-S3-DevKitC-1 (N16R8) |
| Serial chip | CH343 USB-UART, appears as `COM12` |
| Connection | UART USB port (left, on DevKitC-1) |
| Baud rate | 115 200 |
| Ranging config | 8 × 8 zones, **15 Hz**, continuous mode |

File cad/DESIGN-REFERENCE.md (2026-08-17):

# Design reference — every measured number, for building the pod yourself

All values extracted from ST's official STEP (`J5866.step`) or measured with calipers.
Provenance tagged. This is the sheet to design against.

---

## SATEL-VL53L8 (ToF breakout)  — all [ST-STEP], exact

| Dimension | Value |
|---|---|
| PCB | **51.500 × 19.500 × 1.578 mm** |
| VL53L8CX package | 6.400 × 3.030 × 1.750 mm, optical LGA16 |
| Package position on board | X 4.910–7.940, Y 6.550–12.950 |
| **Sensor centre from the near END** | **6.4 mm** |
| Sensor centre across the width | 9.75 mm (centred) |
| Package height above PCB | **1.750 mm** |
| Detection field of view | **45° × 45°** (65° diagonal) — [DS] DS14161 Table 2 |

**Optical axis is NOT the package centre** — [DS] DS14161 Fig. 28:
- Rx axis sits **1.480 mm** from one end, Tx **4.000 mm** further along
- Optical axis is **1.615 mm** from the long edge → **0.100 mm** off package centre
- AN5939 §4 says explicitly: design apertures to the **optical** centre

### Keep-outs — where the components actually are

| | Value |
|---|---|
| **Headers (deep)** | strip **y 0.08–2.62**, running **x 12.77–51.00**, protruding **10.06 mm** below the PCB |
| Everything else below PCB | solder pads only, max **2.13 mm** |
| Tallest thing above PCB | **8.48 mm** (a header); general top clutter to 2.64 mm |

### Clear strip at each edge before you hit a component
*(82 components on top, 36 underneath — this is what limits any rail or lip)*

| Edge | Clear on TOP | Clear on BOTTOM |
|---|---|---|
| Long edge y=0 | **0.91 mm** | **0.08 mm** ← headers sit on this edge |
| Long edge y=19.5 | **1.85 mm** | **3.10 mm** |
| End x=0 | 4.91 mm | 3.55 mm |
| End x=51.5 | 1.46 mm | 0.50 mm |

**Design consequence:** a retaining lip can only grip the **y=19.5** edge, and at most
~1.5 mm. On the header edge, use a **channel that captures the header rib** instead —
it locates the board better than a lip anyway. Board then slides in along its length.

### Cover glass — only if you put a window in front  [AN5939 Rev 3, OFFICIAL]
- Air gap **< 0.5 mm** without a gasket; **> 0.7 mm requires** one
- Air gap + glass thickness **< 1.5 mm**
- **Two circular apertures, concentric with the OPTICAL centres** — beats one oval slot
- Glass tilt ±5° max; transmittance > 87% at 940 nm
- **Simplest compliant option: no window, open apertures.** That is what the pod does.

---

## HBV-1716WA camera — all [CALIPER], measured 2026-07-31

| Dimension | Value | Note |
|---|---|---|
| PCB | **38.0 × 38.0 mm** | agrees with both sources |
| PCB thickness | **1.69 mm** | |
| Mounting holes | **Ø2.3 mm**, **28.2 mm** pitch | derived: 25.9 inner-edge + 2.3 |
| Depth, PCB back → lens front | **25.9 mm** | cap off (28.5 with cap) |
| Lens barrel outer Ø | **17.1 mm** | ⚠ 3 mm bigger than the usual M12 assumption |
| Barrel height above PCB | 24.21 mm | = depth − PCB thickness |

**No official datasheet exists for this camera** — verified negative. Every published
figure we could find was wrong: hole pitch (32 claimed), depth (17.5 claimed), barrel Ø
(~14 assumed). Trust only the measurements above.

### Calibrated optics — `camera/calibration_720p.npz`
```
MJPG 1280x720, cv2.fisheye, RMS 0.3006 px, 19 views
fx = 669.823  fy = 670.075   cx = 620.953  cy = 335.169
D  = [-0.079359, -0.006644, 0.016116, -0.007523]

MEASURED FOV:  H 119.58°   V 63.12°   D 144.02°   (box claims 140° diagonal)
```
**K is resolution-dependent — always capture at 1280×720 or recalibrate.**

---

## Locked mount geometry

| Part | Yaw | Pitch |
|---|---|---|
| Camera | 0° | **22.5° down** |
| ToF left | **22.0° out** (0.5° toe-in) | 22.5° down |
| ToF right | **22.0° out** (0.5° toe-in) | 22.5° down |

**Baseline between ToF optical axes: 34 mm.**

**Why 22.5° down:** largest downtilt keeping the top ray horizontal. Fan spans 0–45°
below horizontal; floor covered from 1.6 m out; at 2 m a person is seen floor-to-1.6 m.

**Why the camera is also 22.5°:** centres the ToF band in frame with symmetric **9.1°**
margins, keeping depth in the middle 14–86% of the image, away from the distorted edges.
20° is *worse* — bottom margin drops to 6.6°.

**Why 0.5° toe-in:** the two fans meet at 0° angularly, but the sensors are 34 mm apart,
so their inner edge rays are parallel and the 34 mm strip between them is seen by
neither — a blind corridor dead ahead. 0.5° crosses the fans at **1.95 m**, closing it,
for only 1° of overlap. Overlap is kept minimal because an unsynced second VL53L8CX
raises the noise floor. (The sensor has a **SYNC pin**, UM3109 §4.15, if it ever matters.)

**Coverage result:** ToF 90° × 45°, entirely inside the camera's view with 14.8° margin
left/right and 9.1° top/bottom. **Depth covers 53.7% of the frame area**; the rest is
camera-only — seen, but with no measured distance.

---

## Practical constraints for the enclosure

| | |
|---|---|
| Behind each ToF | **10.06 mm** of pin, then room for a DuPont housing — **[TBD], measure one** |
| Camera fixing | M2 into printed pilots; **slot them ±1.5 mm** for hole-pitch tolerance |
| FDM clearance around a PCB | 0.35 mm works |
| Wall | 2.8 mm = 3 perimeters at a 0.4 mm nozzle |
| Lid fixing | M3 **heat-set inserts**, not self-tappers — this gets opened repeatedly |
| Cable | strain relief at the exit, or a tug on the tether lands on the camera's USB connector and moves the optical datum |

---

## SOLIDWORKS notes for building it

**In-context design** — put ST's model in the assembly and build around it:
1. Open `J5866.step` → **Save As .SLDPRT**
2. **New Assembly** → insert it (fixes at origin)
3. **Insert Components → New Part**
4. Sketch on a face of the ST board → **Convert Entities** projects its real outline
   into your sketch → **Offset Entities** 0.35 mm → extrude-cut
5. The pocket now matches the real board by construction, not by transcription

**To read any dimension:** **Evaluate → Measure**, click two faces/edges/vertices.
**To see inside:** **View → Display → Section View**.

**Commands you'll need for this part:** Sketch, Extruded Boss/Base, Extruded Cut,
Shell, Fillet, Reference Geometry → Plane (for the 22.5° angled faces), and
Mate in the assembly.

**For the angled seats:** make a **Reference Plane** at 22.5° to the front face, sketch
on that, and extrude normal to it. That is far cleaner than trying to rotate solids.

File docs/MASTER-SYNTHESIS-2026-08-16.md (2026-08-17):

# MASTER SYNTHESIS — all four research streams → one build list — 2026-08-16

Streams: CV stack (`research-sources/cv-stack-research-2026-08-16.md`), red-team
(`cv-redteam-2026-08-16.md`), BLV usefulness (`blv-usefulness-2026-08-16.md`),
aviation protocol (`CALLOUT-PROTOCOL.md`). Items marked **[BUILD NOW]** are
implemented in tonight's autonomous run; **[HW]** blocked on hardware;
**[LATER]** scoped but deferred.

## The three verdicts that reshape what we built

1. **We were 30× too chatty.** Soundscape: 60 s per-object cooldown, silence is
   the default state, hazards only. Our 2 s routine cadence must go.
2. **Numeric distances don't belong in walking speech.** No shipped product
   speaks numbers while walking; proximity = repetition rate (parking-sensor
   pattern). Numbers survive only in on-demand queries.
3. **"Person" callouts are the least-wanted feature; head-height obstacles are
   the product.** 13%/monthly head-level accident rate, unmoved by cane or dog.

## Build list with scopes

### 1. [BUILD NOW] Silence-default hazard engine (replaces routine tier)
Scope: ROUTINE tier removed from autonomous speech. Speaks only: CAUTION
hazards (<1.8 m or closing, upper-row zones only), DIRECTIVE commands, clean /
sensors-lost. 60 s per-object cooldown (approach still re-announces). Stale
items (>1.5 s) dropped at playback, Soundscape-style.

### 2. [BUILD NOW] Two-item grammar, no numbers
Scope: "obstacle, left" / "maybe pole, ahead". Distance moves to the ticker
(#3) and the query (#4). van Erp: 2-item ceiling while walking.

### 3. [BUILD NOW] Proximity ticker (repetition-rate distance)
Scope: parking-sensor tick (short 600 Hz blip) while a hazard is inside 1.8 m
in the path; period scales 1.2 s @1.8 m → 0.15 s @0.5 m. Spectrally sparse,
silence between ticks (bone-conduction masking evidence). Off when clear.

### 4. [BUILD NOW] On-demand scene query (two-tier verbosity, Apple pattern)
Scope: F9 (global) speaks up to 2 nearest objects WITH hedged distances
("person ahead, about 2 meters"), or the verbatim Soundscape empty state:
"There is nothing to call out right now." Numbers allowed here — stationary
aiming context.

### 5. [BUILD NOW] Confidence hedging + no-class honesty
Scope: det conf <0.50 → "maybe X"; ToF-only → "obstacle". Query mode: ranges
spoken as "about X" (association is zone-coarse).

### 6. [BUILD NOW] Cane-blind-spot filter
Scope: hazard triggers require a zone in the UPPER THREE rows (head/torso/
waist band of the 22.5°-down rig). Bottom-row-only returns = cane territory,
rendered but never spoken. (Proper height gating needs the IMU ground plane —
[HW] refinement.)

### 7. [BUILD NOW] Person deprioritized
Scope: selection = nearest hazard regardless of class; person gets no
priority. Tier-1 styling stays visual-only.

### 8. [BUILD NOW] Global controls
Scope: F8 hush (exists) now also silences the ticker; F9 query; `--rate` flag
(default 240; blind users comprehend 8–22 syl/s — headroom is theirs).

### 9. [BUILD NOW] ByteTrack + closing from track history
Scope: worker switches to `model.track(persist=True)` (ultralytics built-in
ByteTrack). Range history keyed by track ID instead of class name — a second
person entering can't inherit the first one's history. Closing = range rate
< −0.5 m/s over the ID's own 1 s window. Distance still re-derived from the
current ToF frame every cycle (red-team #5).

### 10. [BUILD NOW] Brevity trainer
Scope: `camera/callout_trainer.py` — flashcard drill: speaks a brevity
callout, user answers (arrow keys = direction, typed word = object), scores,
10-minute fluency loop. Mirrors how pilots learn brevity. Demo-ready.

### 11. [BUILD NOW] Docs + verification
Scope: headless end-to-end run against live hardware, snapshot, DEVLOG entry,
CV-FUSION-PLAN status update.

### 12. [HW] Temple haptics carry direction+urgency; speech carries identity
HapticHead: 2.6 s vs 6.9 s, 96% vs 54% vs spatial audio. Location > rate >
intensity, ≤2 coding params, PRESCRIPTIVE (signal the path). Blocked on motor
rewire; firmware pins already parked. Also: measure motor SPL at the ear
(masking gate) before committing to head-mounted motors.

### 13. [HW] IMU: ground-plane bbox ranging, drop-off detection, sterile-cockpit
gate (suppress speech during fast head turns), camera↔ToF de-rotation.

### 14. [LATER] Spatialized speech (Klatzky/Loomis: beats spatial language on
time AND working memory). Needs stereo/HRTF pipeline — after bone-conduction
hardware exists.

### 15. [LATER] Feature backlog by demonstrated demand: text/signs on demand
(top task, 15/20) → scene Q&A (23/24 want voice) → dropped objects → bus
numbers → door/last-10-m. Deprioritized permanently: crowd detection, face ID.

### 16. [LATER] Edge port: YOLO26n INT8 → NCNN/OpenVINO benchmark on Pi 5,
Hailo-8L HAT ($70) as insurance; fisheye-augmented fine-tune (0.283→0.698 mAP
evidence); exposure lock for outdoor.

### 17. [STANDING RULES] From red-team, non-negotiable: claims language
("supplementary cue", never cane replacement); cane stays in hand in all
testing; two spotters; silence never means safe; no crossing decisions
("crosswalk ahead, slightly left" — never "walk"); don't look tactical;
outdoor ToF range measured before claimed.

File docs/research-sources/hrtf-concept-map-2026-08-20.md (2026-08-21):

# The HRTF pitch you sent, checked against our research — 2026-08-20

You sent a writeup calling HRTF a potential game changer and asked that
each concept be thoroughly investigated. **They already were** — the full
deep-dive is [[hrtf-spatial-audio-2026-08-20]] (design locked), plus
[[biosonar-2026-08-20]] and [[soundscape-beacon-2026-08-20]]. Here is
every concept from your text, with our verdict and where the evidence
AGREES or CORRECTS it.

| Concept in your text | Our verdict | Where |
|---|---|---|
| HRTF spatialization (ITD/ILD/spectral) | ✅ ADOPTED — azimuth via generic HRTF (KEMAR/slab), precomputed bank | hrtf doc, locked |
| Virtual sound beacon you walk toward | ✅ ADOPTED — Soundscape's actual beacon; WAVs + port plan already in repo | soundscape-beacon doc |
| **Pitch scaling = closer** | ⚠️ **CORRECTED** — pitch is reserved for ELEVATION (3 bands); proximity = pulse RATE. And never brighten near tones: 2–5 kHz is the human-echolocation band we must stay out of (locked −75 dB) | biosonar §audio-band lock |
| **Pulse frequency = proximity** (Geiger counter) | ✅ ADOPTED AND SHIPPED — the TTC ticker already does this (rate = K/TTC), improved: rate encodes time-to-collision, not raw distance, so a stationary you = silence | cv_fusion.py, live |
| **Volume attenuation = distance** | ❌ **REJECTED with evidence** — bats actively remove the loudness cue; blind users are poor at absolute-loudness distance; volume is reserved for CONFIDENCE (Soundscape's only volume use). Distance secondary cue = low-pass filter (muffled = far), which blind users learn instantly | biosonar + hrtf docs |
| Elevation via frequency/tone (bright=high, bass=ground) | ✅ ADOPTED — 3 pitch bands 400 Hz / 1 kHz / 2.5–3 kHz for ground/torso/head | hrtf doc |
| Bone conduction, ears open | ✅ ADOPTED, sharpened — WIRED transducers bonded to the shell (Bluetooth's 260 ms jitter breaks head-tracked audio; consumer band decouples from the IMU) | feasibility-pack §6 |
| Head tracking, low latency | ✅ COVERED — BNO085 at ~100 Hz, IMU extrapolation bridges the ToF's 67 ms; wired audio keeps the loop <30 ms | hrtf doc |
| Dead zones / don't sonify far objects | ✅ SHIPPED — silence-default engine, ticker silent beyond 2 s TTC, cooldowns | cv_fusion.py, live |
| Minimalist sounds (clicks, not music) | ✅ ADOPTED — sparse transients only; sustained/noise textures banned (they deny binaural masking release) | biosonar doc |
| **Personalized HRTF** (ear-photo scanning) vs generic | ❌ **RESOLVED — not worth any effort on our hardware.** BC bypasses the pinna; head-tracking already kills front-back confusion; the correct personalization is a SKULL calibration (our 5-min ILD sweep, now load-bearing). Full verdict + one open design tension (carrier frequency vs echolocation band): [[bone-conduction-spatial-2026-08-20]] | done |
| 3D screen-reader UI (notifications in a hemisphere) | 🕐 Interesting for menus later; not navigation-critical | — |

**Bottom line: your dad's instinct was right and it's already our locked
architecture** — spatial clicks from the obstacle's direction, rate =
urgency, pitch = height, volume = confidence only, wired bone
conduction, IMU head tracking. The two corrections that matter (no
pitch-for-proximity, no volume-for-distance) are evidence-backed, not
taste. The build is unblocked: assets in
`camera/assets/soundscape_beacon/`, port plan in the beacon doc,
transducers on the buy list (~$33).

One caveat on the text's science: "objects reflect high frequencies
differently based on height" is a loose description — real elevation
perception comes from pinna spectral filtering, which is exactly the
part that needs personalization and fails on bone conduction (bypasses
the outer ear entirely). That's WHY our design encodes elevation with
explicit pitch bands instead of trusting HRTF elevation. The agent will
confirm this call.

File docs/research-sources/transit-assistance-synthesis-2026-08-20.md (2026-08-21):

# Transit assistance synthesis — bus ID, doors, platform edge, fusion — 2026-08-20

Companion to [[implementation-guide-2026-08-20]] (same territory, second
independent synthesis — where they agree, confidence is high). Unique
additions here: ALVU, dwell-time budget, hardest-part ranking, TransLink
specifics, read-while-stopped strategy.

## The key answer (both syntheses agree)

**No product today closes the loop "bus 99 arriving — door 3 m to your
right."** Apps do schedules; Aira does it with a paid human; nothing does
it autonomously. The chain — GTFS candidate set → YOLO bus detect → LED
OCR with temporal voting → door localization → spatial-audio + haptic
bearing — is the helmet's defensible novelty.

## 1. Route-number reading — prior systems

- **All_Aboard** (Luo lab, TVST 2024): bus-STOP-sign finder, not a sign
  reader. MobileNetV2 on ~10k Street View images per city (coords from
  GTFS — **training trick directly reusable**). 91% vs 52% Google Maps;
  final gap 1.8 m vs 7.0 m. Failure modes: shadows, angled signs, sign
  leaving FOV on final approach.
- **SRM-OCR (2025)**: super-resolution + Mamba OCR for LED route numbers;
  **85.1% single-frame** on its BusLED-700 dataset (the only public bus
  LED set). Even SOTA needs multi-frame voting.
- Wongta 2018 classical pipeline: 67.9% — how badly classic OCR does.
- **Bus door detection = one paper (Ponnada 2021), zero metrics. Open
  field.**

## 2. Feasibility math (this sensor)

- OCR sweet spot ≈ 30 px capital height (Tesseract tests); deep
  recognizers train at 32 px, ~16–24 px workable with 2× SR.
- Fisheye ≈ 16 px/deg → 175 mm LED char at 10 m ≈ 16 px (marginal), at
  20 m ≈ 8 px (unreadable). **Reliable read ~5–12 m on current sensor; a
  narrow-FOV second camera pushes to 25–30 m.**
- **Design for the STOPPED bus, not the moving one** — dwell gives a
  stationary close-range window of seconds. Announce chain must fit
  inside a 10–30 s dwell; identity at approach, door bearing after stop,
  never during the user's own motion bursts.
- LED PWM flicker capture fix: exposure ≥ one PWM period (≥1/100 s)
  and/or max-composite over 3–5 frames; camera 50/60 Hz anti-flicker does
  NOT cover sign PWM.
- Closed-set GTFS matching converts 85% open-set into **>99% practical**
  (edit-distance over ~5 candidates tolerates heavy OCR noise).

## 3. Model choice

**PARSeq** is the pick (23.8M params, 14.9 ms GPU, IIIT5k 99.0): best
accuracy-per-latency, permissive license, easy fine-tune. ABINet heavier
+ slightly behind; TrOCR 5–10× slower; EasyOCR = CRNN-era; PaddleOCR =
CPU fallback. Full comparison in [[transit-headsign-ocr-2026-08-20]].

## 4. Platform edge

- **ALVU** (Katzschmann/Rus, IEEE TNSRE 2018): ToF array + haptic belt,
  12 blind users, 162 trials, staircase detection validated — the classic
  wearable ToF result to cite.
- EyeCane caution (Sensors 2021): single-point downward sensors — "the
  step appeared to prove the hardest to detect."
- Mizuno & Tokuda 2023 design note: directional tactile pavers placed too
  close to the edge actively MISLEAD — paving detection alone is not a
  safety signal; you need the edge itself.
- Geometry: platform edge = negative obstacle; zones past the edge jump
  >1 m or no-return (drop ≈ 1.1–1.3 m). Detection at 2.5 m at 1.3 m/s =
  ~1.9 s warning — enough IF the downward ToF runs its own ≤100 ms safety
  loop independent of the vision stack. The 8×8 grid gives edge
  ORIENTATION (which zones dropped first) → "edge ahead-left."
- No published platform-edge wearable with metrics — publishable gap.

## 5. Fusion backbone

GTFS-RT + GPS = the backbone (free, city-wide, no infrastructure);
vision confirms identity + last 10 m; ToF last 3 m + safety loop;
beacons/NaviLens only where they exist (none in Vancouver). TransLink:
free API key, GTFS-RT feeds (old RTTI API deprecated). Soundscape's
audio-beacon UX worth copying even though the product died.

## Hardest-part ranking

1. **LED OCR at range on a fisheye** — highest risk, but degradable
   (worst case: "a bus is stopping" + GTFS says only one is due).
2. **Timing/UX** — fit the chain in the dwell window.
3. **Platform edge** — geometrically easy, safety-critical posture.
4. **Bus/door detection** — lowest risk; YOLO fine-tune on Vancouver's
   uniform fleet (a few hundred labeled frames).

## Second-pass additions (same agent, re-run)

- **Multi-bus disambiguation at busy stops** ("which vehicle is the 99"
  when two arrive together) — unsolved anywhere; GTFS-RT position + OCR +
  arrival-order reasoning is a differentiator. Ranked #2 hardest.
- JIS standard puts the warning tile line **80–100 cm from the platform
  edge** — camera fires the first alert at 3–4 m off the tile line; ToF
  is the hard last-line stop. **Latch both cues** (an edge doesn't vanish
  because detection flickered).
- GTFS-RT `current_status=INCOMING` at your stop_id tells you WHEN to
  start scanning, not just what for.
- Commercial destination-sign PWM frequencies (Hanover/Mobitec)
  unverifiable — measure empirically.
- Bus door is always forward of the front axle on North American buses
  (~1×2 m high-contrast opening at 2–8 m — easy YOLO class); the
  door-open **pneumatic hiss** is a fusible audio cue.
- The three announcements no infrastructure provides: WHICH bus arrived
  (platooning), WHERE the door is, WHEN to exit.

## Caveats

NaviLens figures vendor-claimed; Mizuno/Tokuda percentages from
API-reconstructed abstract — re-verify before public use; some §3
comparisons from established knowledge, not fresh citations.

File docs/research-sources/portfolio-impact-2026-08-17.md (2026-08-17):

# Portfolio-impact research — 2026-08-17 (Opus agent, condensed verbatim)

Fourth research stream: how to make the helmet a real usable device AND a
legendary portfolio piece. Audiences that matter (science fairs are CLOSED —
he starts UBC in ~3 weeks): internship hiring managers, UBC design-team/lab
recruiters, the blind community / AT world, and the public.

⚠ TIME-CRITICAL: **UBC Engineering Design Teams recruit the first week of
September** (Imagine UBC + E-Week), explicitly take Science students, and the
helmet is a direct credential for robotics/autonomy teams.

## Ranked actions (impact ÷ hours)

1. **Reframe (2–3 h, gates everything):** "a secondary aid for head-level
   obstacles — the gap the cane leaves." >50% of blind travellers hit their
   head yearly; 13% monthly; unaffected by cane/dog (Manduchi & Kurniawan,
   n=307). Say "complements the cane, never replaces it" unprompted in the
   first 30 s. Know the "Disability Dongle" critique and technoableism by
   name. Never "helping blind people see."
2. **Cut the laptop (20–40 h):** the one move that changes the project's
   CLASS (TRL 4 → 6). Recommended: **Pi 5 + AI HAT+ (Hailo-8L)** — YOLOv8s
   25–35 fps, ~10–12 W, ~2.5–3 h on a 10 Ah pack. Don't chase battery: biped
   NOA is 3 h/battery, .lumen ~2 h — 2–4 h untethered = parity with shipping
   products (quotable).
3. **Three expert conversations (6–10 h) BEFORE more building** — free, no
   ethics gate (consultation ≠ testing):
   - Dr. Kim Zebehazy, UBC O&M program coordinator (kim.zebehazy@ubc.ca) —
     warm intro once enrolled.
   - GTT BC-Yukon monthly meeting (gtt@ccbnational.net) — ask for a
     feature-topic slot; read gttprogram.blog summaries first.
   - Pacific Training Centre for the Blind (blind-led) — go asking "should
     this exist?"
   - Also: CNIB BC Intro-to-AT Zoom (2nd Tuesday; amit.ram@cnib.ca).
   Keep a **decisions log**: expert said X → changed Y. Publish it.
4. **Quantified evaluation on a repeatable course (15–25 h):** imitate the
   2026 Sci Reports ETA protocol (walking-speed fraction, contacts,
   incidents, NASA-TLX). Self + blindfolded volunteers = fine for the
   OBJECTIVE metrics today (state the blindfold-invalidity limitation).
   Target sentence: "14 h across 4 environments, 91% on head-height
   obstacles, 2.3 FP/h indoors, 11/h in sun, 0% through glass."
5. **README as a triage surface (3 h):** 7.4 s screens; managers read the
   README, never the code. Hero GIF of the device WORKING above the fold,
   one-sentence what+why, status block ("untethered prototype, ~3 h runtime,
   not yet tested with blind users"). "Why" appears in only 26% of READMEs —
   that's the differentiator. Deep material into /docs.
6. **90-second demo video with a disclosure line** ("single take, real time,
   no cuts, no speed-ups") — full shot list below.
7. **Embedded Rerun recording on the site (4–8 h):** biped uses Rerun for
   exactly this; reviewers scrub a real walk in-browser. Closest a wearable
   gets to Show HN's "let people try it."
8. **Failure-first writeup (3–5 h):** pull the 5 best DEVLOG stories into
   600–900 words. Hiring managers verbatim: "I'm looking for the bumps in
   the road, not a pretty picture." Keep and BRING the ugly prototypes.
9. **One-button start, auto-recovery, legible state (10–15 h):** watchdog,
   graceful sensor-dropout, <60 s to first useful output. A device that
   visibly RECOVERS reads more real than one that never failed.
10. **Enclosure finish pass (8–12 h, ~$30):** 50 ms first impressions;
    aesthetics correlate with perceived usability more than actual usability
    does. Sand + primer + paint, strain relief, no hot glue. AT-specific:
    bulk/weight and "advertising disability" are documented rejection causes
    — address head-on.
11. **Accessible artifacts (3 h):** audio-described + captioned video,
    screen-reader-clean README, no image PDFs. An AT project failing this is
    self-refuting.
12. **Distribution once 1–8 exist:** Hackaday.io log (log cadence is the
    scored artifact), Sight Tech Global (attend first), Show HN (option
    value).

**Skip:** long PDF portfolios, code dumps, any admissions-facing artifact
(UBC evaluates grades + Personal Profile only).

## The 90-second shot list (keep verbatim)

0:00–0:06 locked-off shot: cane sweeps clean, head stops an inch from an open
cabinet door. Text: "A cane sweeps the ground. Over half of blind travellers
hit their head at least once a year."
0:06–0:13 the helmet on a head, hands empty. "2× ToF · camera · IMU · 3
temple motors. Runs on the helmet. No laptop."
0:13–0:38 **money shot, one continuous take, split frame**: third-person walk
| live world model (points, boxes, which motor fires), synced, latency
counter, burned-in disclosure line.
0:38–0:48 interface honesty: near-silence, one utterance at the decision
point. "It spoke 4 times in this walk."
0:48–0:58 **the deliberate failure**: glass door, show the miss, then the
mitigation or the honest "no fix yet." (Pratfall effect requires competence
FIRST; two-sided arguments need refutation or they backfire — O'Keefe,
107 studies.)
0:58–1:12 course montage + numbers card.
1:12–1:22 one real sentence from the O&M instructor / blind tester — never
faked; decisions log if it hasn't happened yet.
1:22–1:30 device NEXT TO a white cane, equal framing: "It does not replace
the cane. It watches the height the cane can't reach." URL.

## Credibility checklist (condensed)

- Framing: secondary aid, first 30 s; narrow cited problem; no rescue
  language; can name Disability Dongle + technoableism; acknowledge
  head-mount jitter/fatigue critique (Han 2024).
- People: ≥1 O&M professional + ≥1 blind adult (not family), named with
  permission; decisions log published; know Phillips & Zhao (29.3%
  abandonment, mobility aids worst, #1 predictor = ignoring user opinion);
  never recruit informally at org programs; "partner" claims need WRITTEN
  permission.
- Evidence: publish ≥1 unflattering number; baseline = cane alone; report
  cognitive load; ToF limits up front (glass, dark matte, sunlight, <60 cm
  crosstalk); blindfold testing named as an invalid usability proxy.
- Ethics: no human-participant recruitment before approval (TCPS 2 / UBC REB
  once he's enrolled); accessible consent forms (never scanned PDFs); blind
  adults sign for themselves — no guardian countersigning.
- Presentation: honest comparison table vs biped NOA / Glide / .lumen WITH a
  "what ours does worse" column; "Nothing about us without us" understood.

## Flags

- **The 300% rule** (r/embedded): a project you or others ACTUALLY USE beats
  any sophistication. Everything above serves that.
- All artifacts are assembly jobs on the same raw material — process photos +
  the live DEVLOG. Shoot as you go.
- Verify before public use: Manduchi head-injury %s, Phillips & Zhao n; do
  NOT use the untraceable "~75% ETA abandonment" figure.

Full source list in the agent transcript; headline: Ladders eye-tracking, HN
hiring threads, r/embedded threads, TechCrunch "How to fake a robotics demo",
Wistia length data, Rerun×biped, NASA TRL, Disability Dongle (CASTAC), Shew
"Against Technoableism", 2026 ETA RCT (PMC12909938), TCPS 2, UBC design teams.

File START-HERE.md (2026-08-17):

# START HERE — helmet sensor pod

**If you are a fresh Claude session with no context, read these three files before doing
anything else.**

```
1.  cad/MASTER-HANDOFF.md      <- everything. dimensions, angles, decisions, traps.
2.  cad/VERIFY-IT-YOURSELF.md  <- how to check every number in SOLIDWORKS yourself
3.  cad/NEXT-SESSION.md         <- shorter session-to-session notes
```

Two Claude sessions worked on this in parallel on 2026-08-04→07. They were consolidated
into `MASTER-HANDOFF.md` on 2026-08-07 00:30. **That file is the single source of truth.**
Anything that contradicts it is older.

---

## The 60-second version

**Goal:** ToF ↔ camera sensor fusion for an assistive helmet. Project VL53L8CX depth zones
onto camera pixels so every detected object carries a distance in metres.

**Stages 1–2 done** (camera bring-up, intrinsic calibration, RMS 0.30 px).
**Stages 3–4 not started** — extrinsics and live fusion. That is the actual goal, and all
the CAD work exists to serve it.

**The pod:** two SATEL-VL53L8 ToF boards at **±22.5° yaw / 22.5° down**, an HBV-1716WA
camera on the bisector at **0° yaw / 22.5° down**, in a 3D-printed housing that mounts to
a bike helmet via a K&F BH25 ball head.

**The single most important geometric fact:**

> Yaw both ToF sensors **level** to ±22.5°, **group** them, and only then tilt the whole
> group 22.5° down. This gives an **exactly zero seam at every elevation**.
> Pitching each sensor first and then yawing it — same two numbers, different order —
> leaves a 2.02° blind gap at head height and 12° of wasted overlap at the floor.
> Verified: `docs/tof_rigid_group_verify.py`

**Measured camera FOV: 119.58° × 63.12°** (not the ~109/67 that appears in older notes —
that was an extrapolation and it is wrong).

---

## Working files

| | |
|---|---|
| Primary assembly | `cad/solidworks/Assem1double tof test fov.SLDASM` |
| Back up before touching it | `powershell -File cad\backup_solidworks.ps1` |
| Verify exported geometry | `python cad/check_user_assembly.py` |

---

## Read this before giving Reuben any number

**Measure the geometry; do not assert what it should be.** Across this project, every
time a "correct" value was assumed rather than derived, the assumption was the thing that
was wrong. §8 of the handoff lists eight beliefs that turned out false — including three
of the coverage figures, which came from treating yaw and pitch as separable. **They are
not separable.** Compound rotations do not add.

The reliable loop is: **export a STEP → measure it → compare against a computed target.**

---

## Top open items

1. **0.080 mm pinch** at two header shrouds — boards won't slide in. Relief pocket
   0→39 mm along the length, 16.5→20 mm band, 0.5 mm deep.
2. **Mark all FOV cones as Envelope** — they are ~790 cm³ solid bodies and will appear in
   any STL exported from the assembly.
3. **Measure a DuPont housing** — the camera board clears the ToF header pins by only
   10.82 mm and a housing eats into that. Last remaining `[TBD]`.
4. **Re-measure a camera PCB hole** — 2.1 vs 2.3 mm changes the pitch (28.0 vs 28.2).
5. **`Part13`'s `3DSketch1` still has external refs to the TOFSLOT parts** — every TOFSLOT
   edit re-breaks it plus a mate and a sketch. Four reference cascades so far. Lock the
   refs or rebuild the sketch without them.
6. **Open the camera bore** from Ø17.30 to **Ø17.80** — currently only 0.10 mm radial
   clearance on a Ø17.10 barrel, which will not print.

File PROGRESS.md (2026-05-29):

# Project Progress Log

> VL53L8CX × ESP32-S3 Distance Sensor Interface
> Part of an ongoing assistive helmet sensor integration project.

---

## What Has Been Built

### Phase 1 — Firmware (complete)

A working ESP-IDF project that:
- Initialises I2C bus on GPIO1 (SDA) and GPIO2 (SCL) at 1 MHz
- Uploads ST's ULD firmware to the VL53L8CX on boot (~1 s)
- Configures 8×8 zone ranging at 10 Hz in continuous mode
- Streams a compact `DATA:d0,d1,...,d63\n` line to serial every frame
- Clamps invalid or out-of-range zones to `MAX_DISTANCE_MM` (4000 mm) so the host never sees gaps

**Key files:**
| File | Purpose |
|---|---|
| `main/main.c` | Sensor init, firmware upload, ranging loop, serial output |
| `main/idf_component.yml` | Pulls `rjrp44/vl53l8cx ^4.0.0` from ESP Component Registry |
| `sdkconfig.defaults` | Stack size, I2C timeout, log levels |

**Compile-time toggles in `main.c`:**
| Define | Default | Effect |
|---|---|---|
| `STREAM_DATA` | `1` | Emits `DATA:` lines for the Python visualiser |
| `PRINT_GRID` | `0` | ASCII 8×8 grid in serial monitor |
| `PRINT_CLOSEST_ONLY` | `0` | Single "nearest zone" log line |
| `RANGING_FREQ_HZ` | `10` | 1–15 Hz (8×8 mode) |
| `SENSOR_RESOLUTION` | `VL53L8CX_RESOLUTION_8X8` | Or `_4X4` |
| `MAX_DISTANCE_MM` | `4000` | Clamp value for invalid zones |

---

### Phase 2 — Live 3D Point Cloud Visualiser (complete, v2)

A Python script (`visualizer/visualizer.py`) that:
- Opens the serial port and reads `DATA:` lines in real time
- Precomputes a unit direction vector for each of the 64 zones using the sensor's 45° field of view
- Multiplies each zone's measured distance by its direction vector to produce a true 3D Cartesian point
- Applies exponential moving average (EMA) smoothing per zone to eliminate sensor noise
- Drains the serial buffer each frame to always render the newest data, not a stale backlog
- Renders a live scatter plot (matplotlib, dark theme, viridis colormap, colourbar)
- Scatter object created once — updated in-place each frame, no full redraws, no flicker
- Updates at ~10 Hz, matching the sensor's ranging frequency

<p align="center">
  Live 3D point cloud — frame 1916
</p>

```bash
cd visualizer
python -m venv venv
venv\Scripts\activate          # Windows
pip install -r requirements.txt
python visualizer.py --port COM12
```

**CLI options:**
| Flag | Default | Description |
|---|---|---|
| `--port` | `COM12` | Serial port the ESP32 is on |
| `--baud` | `115200` | Must match ESP-IDF default |
| `--max-mm` | `4000` | Z-axis range and colour scale max |

**Smoothing tuning:**  
`EMA_ALPHA` at the top of `visualizer.py` controls the blend between new and historical readings.  
`0.3` (default) = smooth, ~300–400 ms to track a real change. Lower = smoother, higher = more responsive.

---

## Hardware Setup

### Components
- ESP32-S3-DevKitC-1 (N16R8) on AliExpress expansion adapter
- STMicroelectronics SATEL-VL53L8CX breakout board
- 4× 1 kΩ resistors (wired as 2×2 kΩ pull-ups on SDA and SCL)
- 1× 10 kΩ resistor (pull-up for PWREN)

### Confirmed working wiring
| SATEL Pin | ESP32-S3 Pin | Notes |
|---|---|---|
| PWREN | GPIO5 (left, 5th from top) | + 10 kΩ pullup to 3.3V |
| MCLK_SCL | GPIO2 (right, 5th from top) | + 2×1 kΩ in series pullup to 3.3V |
| MOSI_SDA | GPIO1 (right, 4th from top) | + 2×1 kΩ in series pullup to 3.3V |
| NCS | 3.3V | Tied high — selects I2C mode |
| SPI_I2C_N | GND | Tied low — locks I2C mode |
| VDD | 3.3V | Sensor LDO accepts 2.8–5.5V; 3.3V is fine |
| GND | GND | Common ground |

> **Important:** Pull-up resistors connect between the signal line and 3.3V. They are NOT wired in-line between the ESP32 and sensor.

---

## Problems Encountered and Fixed

### 1. OneDrive permission error during `idf.py set-target fullclean`
**Symptom:** `PermissionError [WinError 5] Access is denied` when ESP-IDF tried to delete build artefacts.  
**Cause:** OneDrive was locking files in the project folder on the Desktop.  
**Fix:** Moved the project to `C:\esp-projects\vl53l8cx_esp32\` (outside OneDrive sync).

---

### 2. Wrong target — `esp32` instead of `esp32s3`
**Symptom:** Build configured for the wrong chip family.  
**Fix:** `idf.py set-target esp32s3` — this triggers a full clean and reconfigures CMake for the S3.

---

### 3. `VL53L8CX_Platform` field names were wrong
**Symptom:** Compiler errors: `has no member named 'i2c_port'`, `'scl_pin'`, `'sda_pin'`, `'pwren_pin'`.  
**Cause:** The library's actual `platform.h` uses different field names than ST's generic documentation suggests.  
**Fix:** Read the downloaded `platform.h` directly. Correct fields are:
- `sensor.platform.handle` — `i2c_master_dev_handle_t`
- `sensor.platform.bus_config` — `i2c_master_bus_config_t`
- `sensor.platform.reset_gpio` — `gpio_num_t`

---

### 4. Silent hang after "interface starting"
**Symptom:** ESP32 logged `VL53L8CX interface starting`, then nothing — no error, no sensor detected message.  
**Cause:** The library's I2C read/write timeout defaults to `-1` (infinite wait). The sensor wasn't responding, so the task blocked forever.  
**Fix:** Added to `sdkconfig.defaults`:
```
CONFIG_VL53L8CX_I2C_TIMEOUT=y
CONFIG_VL53L8CX_I2C_TIMEOUT_VALUE=1000
```

---

### 5. 5V pin measuring only 2.1V
**Symptom:** Multimeter on the ESP32's 5V pin read 2.1V instead of 5V.  
**Cause:** The AliExpress expansion adapter board does not route the USB 5V rail to the 5V header pin. Additionally, the native USB port (right side) does not power the board the same way the UART port does.  
**Fix:** Powered the sensor from the 3.3V pin instead. The SATEL-VL53L8CX's onboard LDO accepts 2.8–5.5V input, so 3.3V works correctly.

---

### 6. Sensor still not detected — root wiring issue
**Symptom:** Even with 3.3V power and correct pull-ups, sensor not detected.  
**Cause:** SDA and SCL jumper wires were plugged into the wrong rows on the breadboard — into the row for `RXN1` instead of `GPIO1` and `GPIO2`.  
**Fix:** Moved the wires to the correct GPIO rows. On the DevKitC-1, GPIO1 is the 4th pin from the top on the right side, GPIO2 is the 5th pin from the top on the right side.

---

### 7. `idf.py monitor` blocks the serial port
**Symptom:** Python visualiser throws `SerialException: could not open port COM12`.  
**Cause:** ESP-IDF monitor holds the COM port open exclusively.  
**Fix:** Close monitor with `Ctrl + ]` before running the Python visualiser. Only one program can hold the port at a time.

---

## Important Lessons Learned

- **Read the actual downloaded source.** The library's `platform.h` and example `main.c` are in `C:\esp-projects\vl53l8cx_esp32\managed_components\rjrp44__vl53l8cx\` after first build. Always check there rather than relying on generic ST documentation.
- **I2C timeouts are disabled by default.** Without `CONFIG_VL53L8CX_I2C_TIMEOUT`, a missing or mis-wired sensor causes a silent hang, not an error.
- **Pull-up resistors are parallel, not series.** They connect from the signal node up to Vcc. A correct pull-up topology lets either device pull the line low while the resistor pulls it back high when released.
- **Use the UART USB port (left) for flashing.** The native USB port (right) is for USB-OTG. The 5V pin only outputs correctly from the UART port.
- **The DATA: prefix pattern is clean.** By prefixing streaming data with `DATA:`, the Python parser can ignore all `I (nnn) TAG: ...` ESP_LOG lines without needing to suppress them in firmware.

---

## Visualiser Issues Encountered and Fixed (v2)

### Issue 1: Points flickering and occasionally disappearing
**Root cause:** `ax.clear()` was called every frame. This destroys and recreates every matplotlib artist — axes, labels, tick marks, pane backgrounds, grid lines — 10 times per second. When a single redraw took longer than 100 ms (the sensor's frame interval), the serial buffer backed up with unread `DATA:` lines. The next `readline()` then returned a partial or empty line, `parse_data_line` returned `None`, the render was skipped entirely, and the points appeared to vanish.

**Fix:** Create the scatter object once before the loop. Update its data in-place each frame:
```python
sc._offsets3d = (xs, ys, zs)   # move points
sc.set_array(smoothed)          # recolour by distance
fig.canvas.draw_idle()          # redraw only what changed
```
All axis styling (limits, labels, pane colours, view angle) is set once before the loop and never touched again.

---

### Issue 2: Serial buffer backlog — always rendering stale data
**Root cause:** If matplotlib rendering takes >100 ms, unread frames pile up in the OS serial buffer. The visualiser was always rendering the *oldest* buffered frame, not the current one — meaning the display could be several frames behind reality.

**Fix:** After receiving one valid frame, drain `ser.in_waiting` bytes immediately to discard stale frames and keep only the newest:
```python
while ser.in_waiting:
    newer = ser.readline().decode("utf-8", errors="ignore").strip()
    parsed = parse_data_line(newer)
    if parsed is not None:
        distances = parsed   # always keep the most recent
```

---

### Issue 3: Raw sensor noise causing jumpy points
**Cause:** The VL53L8CX returns readings that vary ±10–30 mm frame-to-frame on a static scene. Rendering raw values directly made individual points visibly jump each frame.

**Fix:** Exponential moving average (EMA) per zone:
```python
EMA_ALPHA = 0.3
smoothed = EMA_ALPHA * distances + (1.0 - EMA_ALPHA) * smoothed
```
Weight 0.3 on the new frame, 0.7 on the running average. Eliminates noise flicker while still tracking real movement in roughly 3–4 frames (~300–400 ms lag).

---

## Visualiser v3 — PyQtGraph rewrite

v2 fixed the flicker and stale-data problems but two complaints remained:

1. **Mouse-drag rotation was sluggish.** `mplot3d` is software-rendered, and every drag event had to wait its turn behind the data loop's `draw_idle()`. The 3D scatter was effectively starving the GUI thread.
2. **Frame-render lag was still ~one frame stale.** v2's drain ran *after* `readline()`, so when a redraw exceeded the 100 ms frame interval the next iteration's `readline()` pulled the OLDEST queued line, then drained anything queued after that. Net result: the visualiser was always rendering one frame behind the sensor.

### Fixes

| Fix | Evidence |
|---|---|
| Renderer swapped from `mplot3d` → PyQtGraph (`GLViewWidget` + `GLScatterPlotItem`) | Qt + OpenGL is GPU-accelerated; rotation is no longer coupled to data redraws. |
| Serial reader moved to a `QThread`; new frames delivered via Qt signal | `readline()` no longer blocks the GUI event loop. Mouse events get serviced even mid-frame. |
| Drain order flipped: drain *first*, then process the newest valid `DATA:` line | Provable from the code — the previous `readline → drain` order always pulled the oldest queued frame. |
| `EMA_ALPHA` 0.3 → 0.6 | EMA settles 95% in `−ln(0.05) / −ln(1−α)` samples. 0.3 = ~9 frames (~900 ms at 10 Hz), 0.6 = ~3 frames (~300 ms). |
| Phantom back-wall hidden (firmware sentinel == `MAX_DISTANCE_MM` masked to NaN, drawn with α=0) | Firmware [`main.c`](main/main.c) clamps invalid zones to 4000 mm so the host never sees gaps; the visualiser must filter them or they look like a real wall. |

### Spec note (and a correction)

VL53L8CX FoV per the ST datasheet is **65° diagonal, 45° horizontal/vertical**. Earlier triage suggested the 45°/8 = 5.625° per-zone constant might be wrong; verifying against ST's product page and the data brief confirms the constant is correct. Comment added in source so this isn't "re-fixed" later.

---

## Visualiser v4 — scientific look + sensor model + animated ToF rays

v3 was responsive but visually plainer than the matplotlib version. v4 brings back the scientific look and adds physical context:

- **Side colour bar** (viridis, mm scale) restored as a `pyqtgraph.GraphicsLayoutWidget` next to the GL view, with a labelled right axis.
- **X / Depth / Y axis arrows** in red / green / blue from the origin, with text labels (`GLTextItem`) at the endpoints and tick text every 1000 mm along the depth axis.
- **Sensor body** modelled as a flat dark `GLMeshItem` rectangle at the origin with a bright `GLLinePlotItem` lens ring and a "VL53L8CX" label.
- **45°×45° FoV frustum** (4 corner rays + back square) marking the actual physical cone the sensor sees.
- **Animated ToF beams** — one `GLLinePlotItem` line per zone, origin → endpoint, updated every frame. Each beam is coloured by the same viridis hue as its endpoint and uses an alpha gradient (10% at the lens, 55% at the point) so it reads as light emitted from the sensor. Invalid zones drop to α=0. The beams visibly pulse with the live data, which is exactly what a multizone ToF sensor is doing physically.
- **Status bar** showing live frame count, valid-zone count out of 64, and mean valid distance.

### Demo clips

- `visualizer/progress_demo.mp4` — 10-second before/after clip cut from screen captures: 3 seconds of the v1/v2 matplotlib version, 7 seconds of the v3/v4 PyQtGraph version. Shows the rotation responsiveness gain and the new sensor + ray visualisation.
- `visualizer/progress_demo_v4.mp4` — 5-second focused capture of the v4 view in motion (sensor body + frustum + animated ToF rays at 15 Hz post-firmware bump).
- `visualizer/progress_demo_v6.mp4` — 10-second capture of the final v6 view: world-frame point memory wrapping around the sensor as it pans, fading trajectory trail, and the live ToF rays at 15 Hz.

### Things that did NOT need fixing (despite earlier suspicion)

- Direction-vector normalisation: max magnitude error at the corner zones is ~0.8% — negligible.
- FoV constant: confirmed correct (45° per axis).

---

## Firmware bump — 15 Hz ranging

Bumped `RANGING_FREQ_HZ` in `main/main.c` from 10 to 15 — the datasheet maximum for 8×8 mode. Frame interval drops from 100 ms to ~67 ms, giving the visualiser 50 % more samples per second and shrinking the EMA's wall-clock settle time accordingly. Confirmed by sniffing `DATA:` lines on COM12 — measured 15.2 Hz. Power and serial bandwidth headroom are both still comfortable at 115 200 baud.

---

## Visualiser v5 — experimental 6-DOF relative pose estimation

Pure-experiment addition. With only the VL53L8CX (no IMU yet), the only way to estimate sensor motion is to use the depth data itself. v5 implements per-frame rigid registration on the 64-point cloud, integrates the result, and draws the trajectory.

### Algorithm — Kabsch / Procrustes / SVD

For each new frame, given paired point sets P (frame k−1) and Q (frame k):

1. Subtract centroids: `Pc = P − mean(P)`, `Qc = Q − mean(Q)`.
2. Cross-covariance: `H = Pc.T @ Qc`.
3. SVD: `U, S, Vt = svd(H)`.
4. Reflection guard: `d = sign(det(Vt.T @ U.T))`, `R = Vt.T @ diag(1, 1, d) @ U.T`.
5. Translation: `t = mean(Q) − R @ mean(P)`.

This yields the rotation + translation that best aligns Q to P. The sensor's per-frame motion δT is the inverse: `δR = R.T`, `δt = −R.T @ t`. World-frame cumulative pose composes as `T_world(k) = T_world(k-1) · δT`.

### Same-zone correspondence + small-motion assumption

We pair zone *i* in frame k−1 with zone *i* in frame k. That's the correct pairing **only** under the small-motion assumption — between frames at 15 Hz (~67 ms) each zone still observes approximately the same world point. Fast motion breaks this; large fitted Δt or ΔR almost always means broken correspondence rather than real motion, so the estimator gates on:

- `max_translation_mm = 300 mm/frame`
- `max_rotation_deg = 20°/frame`

Gated frames break the chain (cumulative pose holds steady) instead of corrupting it.

### Visualisation

A `GLLinePlotItem` traces the cumulative path of the sensor's origin in world frame, with a small head sphere marking the current position. Every frame the trail is transformed into the *current* sensor frame so it appears to flow behind the sensor as it moves through space. Status bar reads out cumulative translation (mm), cumulative rotation (deg), and the per-frame rejection count. **R** resets the pose and clears the trail.

### Limitations

- 64 points is sparse for ICP-style work; expect noticeable drift over time.
- No yaw reference: rotating the sensor around gravity is unobservable from depth alone (the floor's depth map doesn't change). The estimator will report some drift here that is mostly noise.
- 0/64 valid zones (e.g. covered sensor, loose connection) → estimator pauses cleanly.
- This is not a substitute for the planned IMU integration in Phase 3 — it's a proof of concept that the depth data alone carries motion information.

---

## Visualiser v6 — world-frame point memory + fading trail

Two visual issues with v5:

- The live point cloud was always pinned in front of the sensor in a 45° cone. Looked the same regardless of how the sensor moved — past observations weren't preserved.
- The trajectory trail kept growing forever, eventually becoming a thick yellow tangle that obscured the scene.

### Fixes

**Accumulated world-frame cloud.** Each frame, the valid sensor-frame points are transformed into world frame using the v5 pose estimate (`world_p = R_world · sensor_p + t_world`) and pushed into a rolling deque (~6 s × 15 Hz = 90 frames). For rendering, every entry is transformed back into the *current* sensor frame each tick and given an alpha proportional to its age (newest = ~0.35, oldest = ~0). The visual effect: as the sensor pans, old observations stay where they were physically measured and slide off to the side instead of staying glued to the front cone — the cone effectively wraps around the sensor.

**Fading trajectory trail.** The trail is now capped at ~5 s of history (75 points at 15 Hz). Each vertex carries its own alpha — `linspace(0.05, 0.95, n)` from tail to head — so the line fades from invisible at the back to bright yellow at the sensor's current position. No more growing tangle.

**R key clears both** the trail and the accumulated cloud.

### Caveats

The accumulated cloud's quality is bounded by the pose estimator. If the pose drifts (which it will, especially in yaw), past observations smear by the drift amount when the sensor returns near a previously-scanned region. The 6-second cap keeps drift damage local — anything older has faded out by then. With an IMU added later, drift drops sharply and the same code becomes a useful sparse 3D map.

---

## Status — paused on hardware

**v6 is the final visualiser iteration on the current hardware.** With only the VL53L8CX (no IMU, no second sensor, no compass), every avenue for improvement has been pushed as far as the depth data alone allows:

- 15 Hz is the datasheet maximum for 8×8 mode.
- 64 zones at ±10–30 mm noise is the sensor's resolution and accuracy ceiling.
- Yaw is unobservable from depth alone, so the v5 pose estimator drifts on rotation around gravity. No firmware or visualiser change can fix this — it is a sensing-physics limit, not a software one.
- The accumulated world-frame cloud in v6 is bounded by that same drift.

Further visualiser work is **paused until the IMU arrives.** Once the IMU is wired onto the same I2C bus, the next iteration will fuse accelerometer + gyro into the pose estimator (gravity gives absolute pitch + roll, gyro integration plus accel-gravity correction tightens yaw), which unlocks:

- A genuine 3D scan that holds shape over time without drift.
- Heading-stable trajectory, sufficient for helmet-tracking experiments.
- The interpolated topographic surface and proximity overlay ideas below — both currently bottlenecked by drift, not by rendering.

## Planned Next Steps (queued for IMU integration)

1. **Sensor fusion** — accelerometer/gyro + ToF, replacing the depth-only Kabsch estimator with a complementary or Madgwick filter.

2. **Interpolated topographic surface** — bicubic interpolation across the 8×8 grid, rendered as a smooth 3D mesh with viridis colouring and contour lines every 100 mm.

3. **Silhouette / proximity detection overlay** — highlight zones below a configurable threshold distance to indicate objects or obstacles.

4. **Integration into assistive helmet** — combine with additional sensors (wider-angle ToF or ultrasonic) for fuller spatial awareness.

---

## Commit History

| Commit | Description |
|---|---|
| `dd5b9ab` | Initial working interface for VL53L8CX on ESP32-S3 |
| `fb2a326` | Add hardware photos and update README with images |
| `d19ec5a` | Add streaming data output and 3D point cloud visualiser |
| `6f3ee04` | Add PROGRESS.md documenting project history and lessons learned |
| `598f134` | Fix visualiser flicker, buffer backlog, and point noise (v2) |
| `041fb81` | Add point cloud screenshot and rewrite visualizer README |
| `1190a8f` | Document v2 visualiser improvements in PROGRESS.md |
| `cf574b6` | Visualiser v3: rewrite on PyQtGraph + threaded serial reader |
| `62f33f0` | Visualiser v4: scientific axes + sensor model + animated ToF rays |
| `20c5d68` | Document v3 + v4 visualiser iterations and add progress demo clip |
| `568aa5c` | Bump VL53L8CX ranging frequency 10 → 15 Hz (firmware) |
| `4520f99` | Visualiser v5: experimental 6-DOF relative pose estimation (Kabsch) |
| `5462d60` | Document v5 + 15 Hz bump and add v4 motion demo clip |
| *(next)*  | Visualiser v6: world-frame point memory + fading trail |

---

## v7 → v11 — see README.md

**This document captures v1–v6 in depth.** v7 onward (WiFi streaming, OTA, buzzer alert, v9 sensor characterization sweep, v10 wearable/body-frame/per-row-threshold/phone viewer, v11 directional haptic ring) are documented in full inline in [`README.md`](README.md), with the development log structured as one iteration section per version. Single source of truth for everything after the IMU-or-bust pause is the README — this PROGRESS log is kept for v1–v6 historical reference only.

### v11 — directional haptic ring (2026-05-28, current)

Three ERM coin motors added to the helmet rim, driven by 2N3904 NPN low-side switches from GPIOs 7 / 15 / 16. Physical mapping verified via single-pin OTA pulse test:

- **GPIO 7  = CENTER (forehead)**
- **GPIO 15 = RIGHT temple**
- **GPIO 16 = LEFT temple**

Full bring-up log in [`docs/haptics-bringup.md`](docs/haptics-bringup.md). Column→motor mapping logic with dominance weighting (research-backed in [`docs/research-sources/directional-haptics-mapping.md`](docs/research-sources/directional-haptics-mapping.md)) is **next up** — design decisions locked in, code not yet written. See `todo.md` Queued #1.

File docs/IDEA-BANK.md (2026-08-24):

# IDEA BANK — priority-ranked, expandable — rebuilt 2026-08-21

Every idea is a **collapsed dropdown** — click to expand for the what/why/
how. Ranked by priority (P0 → P3), best-first within each tier. Mark your
verdict on the title line: ✅ build / ❌ skip / 🕐 later. Effort: S <1
session · M 1–3 · L project. Sources live in `research-sources/`.

Legend: ✅ = you already ruled build · ⚖ = your call pending · 🕐 =
deferred with trigger · ❌ = ruled out (kept with reasons at the bottom).

---

## P0 — status (all resolved 2026-08-21)

> [!success]- ✅ IMU mount calibration — **DONE 2026-08-21**
> Voice-guided two-pose gravity calibration, verified all three axes,
> committed. Unlocks every IMU feature below (head-clearance, floor
> rejection, leveling accuracy, beacon tracking).

> [!note]- 🕐 VL53L8CX sunlight bench test [S] — deferred; trigger = before trusting any outdoor feature
> **What**: measure real max range indoors / shade / direct sun with a
> tape measure and cardboard target (15 min).
> **Why**: datasheet says range collapses 2.4 m (dark) → ~1 m at office
> brightness; sun is 10–20× brighter. Every outdoor warning distance
> (head-clearance 2 m, drop-off 2.5 m) assumes range we may not have.
> **Source**: [[platform-edge-safety-2026-08-20]], [[QA-2026-08-21]]

> [!note]- 🕐 CLOSEST vs STRONGEST target order A/B [S] — deferred; trigger = CV distances flapping
> **What**: firmware already runs CLOSEST. A/B = 20 s captures of a thin
> pole in front of a wall under each order; compare stability + pole
> visibility.
> **Why**: STRONGEST makes a 3 cm branch silently invisible (background
> wins); CLOSEST can flap on weak near returns. Multi-target mode can
> give BOTH: closest return for safety, strongest for stable CV ranges.
> **Source**: [[QA-2026-08-21]] §1, [[implementation-guide-2026-08-20]]

---

## P1 — highest impact per session (build next)

> [!note]- 0. Adaptive haptic intensity in tight spaces (field walk 2026-08-24)
> **What**: scale haptic strength down when the passage is narrow on BOTH
> sides (doorway squeeze, tight corner) — full-strength buzzing on both
> temples while deliberately threading a gap is alarm without information.
> Possible shape: when left AND right ranges are short and symmetric,
> drop to the walkable-tunnel centering encoding instead of raw proximity.
> **Also from the same walk**: helmet haptics run standalone in firmware
> (fire whether the laptop is on or not) — by design (safety layer never
> depends on the laptop), but consider a phone-toggleable standby.
> **Source**: Reuben's first full walkthrough, 2026-08-24.

> [!note]- 1. ✅ Soundscape audio beacon — **BUILT, needs live camera test** [key `g`]
> **What**: lock a detected object; Soundscape's actual 4-region musical
> beacon (their MIT WAVs) leads you to it; arrival melody at 1 m.
> **Left to do**: first live test with camera + verify the lost-target
> IMU sign (marked in code — flip one sign if the beacon runs the wrong
> way when the object leaves frame).
> **Source**: [[soundscape-beacon-2026-08-20]], camera/beacon.py

> [!note]- 2. Head-clearance check in the GRAVITY frame [M] — your ✅ rule, done right
> **What**: warn when overhead clearance above the top ToF rays (in
> world coordinates, IMU-compensated) drops below your 10–15 cm margin.
> **Why gravity frame**: head pitch in normal walking is ±8° = ±140 mm
> at 2 m — more than the whole margin. Fixed "top row" is wrong at the
> definition level; prior art (Muñoz 2025) dodged this — it's our
> novelty claim. Alerts: first ≥2 m, hard 1.2 m.
> **Evidence**: 13% of blind people have head-level accidents monthly;
> cane AND dog users equally. ADA's 27–80 in band = "cane misses it,
> code says it shouldn't be there."
> **Source**: [[implementation-guide-2026-08-20]] §2

> [!note]- 3. Walkable-tunnel haptics [M] — .lumen's best mechanism, unclaimed
> **What**: a virtual corridor along your path; temple motors fire ONLY
> when you drift toward its walls. Silence when centered.
> **Why**: kills haptic fatigue vs continuous steering cues; described
> in .lumen's patent but NOT claimed — free to use. Fits our v11
> firmware directly.
> **Source**: [[patents-stripmine-2026-08-20]]

> [!note]- 4. GTFS-Realtime fusion [S-M] — cheapest huge win, nobody ships it
> **What**: TransLink's free live feed tells us which buses serve this
> stop and which is arriving NOW → open-set LED reading becomes picking
> between ~5 known strings (>99% practical accuracy).
> **Note**: with camera #2 ruled out, this powers stop-context +
> arrival announcements rather than long-range sign reading — still the
> backbone of any transit feature.
> **Source**: [[transit-gtfs-navilens-2026-08-20]]

> [!note]- 5. 🕐 Glass detection — DEPRIORITIZED by your ruling 2026-08-22
> **Your reasoning (sound)**: head-level glass that isn't also at cane
> level basically doesn't exist — glass walls/doors reach the floor,
> and the cane is always alongside. Collision risk ≈ handled.
> **What survives (small)**: glass still corrupts DATA — a pane can
> return the room BEHIND it (phantom far reading where a wall is) or a
> mirror can create phantom obstacles. Keep the cheap `target_status`
> filtering we already do; the full detector (CV segmentation, TOPGN
> signature, ultrasonic #36) waits for evidence it's needed.
> **Source**: [[ultrasonic-mmwave-glass-2026-08-20]], [[QA-2026-08-22]]

> [!note]- 6. ✅ Signage / label OCR engine [M] — one engine, three features
> **What**: PARSeq text recognition (15 ms/crop) beside YOLO. Powers:
> label-reading-in-hand (your ✅), close signage à la Apple (your ✅),
> and **find-by-text** ("find Heinz" — your idea) at ~0.5–3 m.
> **Limit**: camera #2 ruled out ⇒ close range only (a 15 cm sign
> character is readable to ~3–5 m on the fisheye).
> **Source**: [[transit-headsign-ocr-2026-08-20]], [[QA-2026-08-20-part2]]

> [!note]- 7. Moving-vehicle interlock + blocked-path honesty [S]
> **What**: (a) never emit "step forward" unless ToF confirms zero
> closing velocity N frames — separate auditable module; (b) when fully
> blocked: stop and SAY so, never push through (Glide's behavior).
> **Why**: small code, disproportionate consequence; the one error
> class that ends trust permanently.
> **Source**: [[implementation-guide-2026-08-20]] §3b, [[glidance-deep-dive-2026-08-20]]

> [!note]- 8. Per-user ILD skull calibration [S] — now load-bearing
> **What**: 5-min lateralization sweep through the bone-conduction pair
> measuring YOUR skull's left-right crosstalk (varies ~40 dB between
> people); sets the pan exaggeration.
> **Why**: this is the scientifically correct "personalization" for BC
> — ear-photo HRTF personalization buys nothing (BC bypasses the ear).
> **Source**: [[bone-conduction-spatial-2026-08-20]]

> [!note]- 9. On-track reassurance ping + pulse-count haptic vocabulary [S]
> **What**: faint periodic pulse = "system alive, path clear" (silence
> never means dead battery); N pulses = semantic channel (2 = hazard
> ahead, 3 = turn coming); anti-lock-style burst texture = urgency.
> **Rule**: ≤2 motors simultaneously, prefer 1 — recognition falls
> 93% → 78% with 3-motor patterns (GuideTouch, n=22, p<1e-6).
> **Source**: [[patents-stripmine-2026-08-20]], [[guidetouch-2026-08-20]]

---

## P2 — strong, after P1

> [!note]- 10. ✅ Queue detection + progress [M] — LineChaser pattern
> **What**: find the end of the line, "line moved, step forward," "you're
> next." Proven at CHI 2021 with exactly our sensors (camera + depth +
> person tracking).
> **Source**: [[QA-2026-08-20]], [[transit-bus-boarding-litreview-2026-08-20]]

> [!note]- 11. ✅ Empty-seat finding [M] — with the reframe decision open
> **What**: camera finds chairs, depth says which are empty, beacon
> guides. YOUR ✅.
> **The catch**: bags/coats on chairs are COCO's two worst detection
> classes — a false positive = sitting on someone's laptop. Research
> recommends the "describe the seating" variant (bearing + distance +
> honest confidence, you pick, beacon guides). Your call which version.
> **Source**: [[feasibility-pack-2026-08-20]] §4

> [!note]- 12. ✅ Crosswalk alignment [M-L] — BEV pipeline + Glide's spoken bookends
> **What**: bird's-eye rectify (IMU gravity) → stripe fit → geometric
> validators → LATCH heading at curb → closed-loop haptic correction
> across (veer is a random walk — open-loop pointing is useless past
> 4 m). "Approaching road" → you decide → "crossing complete."
> **The real project**: bearing precision (±3° needed); build the
> ground-truth rig first. Wet night = gyro-only fallback.
> **Never**: go/no-go calls. Alignment only.
> **Source**: [[implementation-guide-2026-08-20]] §4

> [!note]- 13a. ✅ Door UX ruling 2026-08-22: scan-and-select, never guess
> **Your concern**: "how does it know which door I want — don't guide
> me to random doors." **Answer**: Glide's shipped pattern — announce
> candidates ("two doors: twelve o'clock 8 m, two o'clock 15"), YOU
> pick, beacon locks. Signage OCR breaks ties. Full navigation stays on
> the phone (even Soundscape's creator delegates to Google Maps);
> helmet owns the last ~10 m only. **Research DONE 2026-08-22**: full
> build spec in [[last-meter-doors-2026-08-22]] — OSM entrances = bonus
> only (live query: downtown Vancouver <18% coverage, Dunbar ZERO);
> order candidates by destination bearing not distance; ≤3 + "more";
> spatialized terse speech; our multi-candidate list may out-do Glide's.
> **Source**: [[glidance-deep-dive-2026-08-20]], [[last-meter-doors-2026-08-22]]

> [!note]- 13. Terminal guidance to doors [L] — the U1 flagship
> **What**: detect door → ToF confirms real opening (depth behind) +
> range → beacon/haptics steer you to it. Door STATE from geometry
> (coplanar with wall = closed); hinge side from handle position; read
> the sign next to it (Apple's pattern).
> **Reality check**: unseen-environment door detectors are 13–48 mAP;
> our own capture loop (auto-label → correct → nightly fine-tune) is
> what makes it work: 15% local data took 20→76 mAP.
> **Source**: [[implementation-guide-2026-08-20]] §1

> [!note]- 14. Drop-off detection [M] — the one terrain carve-out
> **What**: down-ToF ground-plane-absent detection (stairs down, curbs,
> platform edges). Canes miss 1-in-5 to 1-in-3 drop-offs even with good
> technique.
> **Honest spec**: "extends cane drop-off coverage, degraded in full
> sun" (pending the sunlight test). False-positive discrimination
> (black mats, puddles) is the hard part, not detection.
> **Source**: [[feasibility-pack-2026-08-20]] §2, [[platform-edge-safety-2026-08-20]]

> [!note]- 15. Trajectory-prediction alerts [M] — biped's one good idea
> **What**: warn only on collision COURSE, not proximity — ByteTrack
> velocity + your own motion → per-object TTC; .lumen's 0.3 m
> predicted-trajectory gate as the threshold.
> **Source**: [[patents-stripmine-2026-08-20]], indoor-nav research

> [!note]- 16. Intervention logging → data flywheel [S-M] — Glidance's fleet learning at N=1
> **What**: 60 s ring buffer (video + ToF + IMU + what the system
> said); auto-save clips on: ToF/CV disagreement, user override,
> near-miss, low confidence, manual "flag that." Weekly: label failures
> → eval set first → retrain → replay old clips as regression tests.
> **Why**: every stumble becomes a training label; the telemetry schema
> is what turns one helmet into a fleet later.
> **Source**: [[glidance-deep-dive-2026-08-20]] (openpilot-verified pattern)

> [!note]- 17. Pose-aware floor rejection + speech gate on fast head turns [S each]
> **What**: (a) expected-floor-per-zone from live pitch replaces the
> crude row filter — kills look-down false alerts; (b) suppress routine
> speech while the head turns >~100°/s (sterile cockpit).
> **Unlocked by**: the IMU cal you just did.
> **Source**: [[imu-uses-2026-08-17]]

> [!note]- 18. Tap-to-query + auto-silence in vehicles [S each]
> **What**: the BNO085's on-chip tap detector = F9 without a keyboard
> (helmet shell is a good tap substrate); on-chip activity classifier
> silences callouts in cars/buses automatically.
> **Source**: [[imu-uses-2026-08-17]]

> [!note]- 19. Interrogation interface [M] — "tell me more"
> **What**: layered on-demand depth: F9/tap gives labels → repeat gives
> ranges → repeat gives details. The #1 requested interaction property
> in BLV studies. Around-Me variant: 4 quadrants, max ONE item each
> (Soundscape's pattern).
> **Source**: [[blv-daily-life-2026-08-18]], [[soundscape-beacon-2026-08-20]]

> [!note]- 20. Drop alarm [S] — helmet beeps when it falls off
> **What**: clip/tether or IMU-freefall trigger → helmet chirps so a
> blind owner can find it. A dropped helmet is invisible to its owner.
> **Source**: [[guidetouch-2026-08-20]]

> [!note]- 21. Distance low-pass + confidence dimming on audio [S each]
> **What**: muffled = far (blind users learn it instantly); dim the
> tick/beacon when sensor confidence drops — volume carries CONFIDENCE,
> never distance (bats actively remove the loudness cue).
> **Source**: [[hrtf-spatial-audio-2026-08-20]], [[biosonar-2026-08-20]]

> [!note]- 22. Steps instead of meters + clock-face option [S each]
> **What**: user-calibrated stride → "about six steps" near (ObjectFinder
> users preferred steps close-up); clock-face vs left/right as a
> setting (preference split 7/15 vs 6/15 in studies).
> **Source**: [[feasibility-pack-2026-08-20]] §1, [[CALLOUT-PROTOCOL]]

---

## P3 — future / gated / on-trigger

> [!note]- 23. 🕐 Teach-and-repeat route retrace [L] — your ruling: interesting, not #1
> **What**: walk a route once (with a sighted guide), IMU + camera
> odometry records landmarks; later the beacon/tunnel replays it. NOT
> full SLAM. Glide ships this pattern ("walk once or twice").
> **Source**: [[patents-stripmine-2026-08-20]], GuideNav

> [!note]- 24. 🕐 Companion beacon [M] — your ruling: low priority, demand thin
> **What**: voice-locked "where's my person" re-finding (companion
> stepped away), ≤4 m, fails loudly to the cane. NOT continuous
> locomotion-following (nobody asks for that; the elbow beats it; a
> UWB tag beats vision anyway). CHI 2026 demand is group/semi-static.
> **Source**: [[feasibility-pack-2026-08-20]] §5

> [!note]- 25. Dropped-object mode, narrowed [M]
> **What**: head-aim floor search for phone/wallet/bottle-sized items
> ONLY (keys/coins are below the detection floor at 720p). Speech =
> object-distance-direction, steps near, separate azimuth/elevation
> channels — never scalar warmer/colder.
> **Honest**: AirTags dominate the tagged case; our niche = untagged
> unexpected drops, hands-free.
> **Source**: [[feasibility-pack-2026-08-20]] §1

> [!note]- 26. Bus/transit features beyond GTFS [L] — partially blocked by no-camera-2
> **What survives**: stop-finding (All_Aboard pattern), arrival
> announcements from GTFS-RT, bus-door localization once stopped
> (~2–8 m, zero prior art = novelty claim), LineChaser boarding cue.
> **What's blocked**: route-number OCR at range (needs pixels we don't
> have).
> **Source**: [[transit-assistance-synthesis-2026-08-20]]

> [!note]- 27. Platform-edge safety loop [M] — after the sunlight test
> **What**: independent ≤100 ms ToF loop; drop-off band signature +
> edge orientation ("edge ahead-left"); camera segments the warning
> tile line for early speech; latched alerts. 76% of blind respondents
> have fallen off a platform; no published wearable baseline.
> **Source**: [[platform-edge-safety-2026-08-20]]

> [!note]- 28. Storefront-vs-display-window ruleset [M]
> **What**: entrance = walkable floor continuity across the threshold;
> window = sill at 0.4–1 m; + metric width class + handle height + OCR.
> No published work — ours to invent. Scored ruleset, not learned.
> **Source**: [[implementation-guide-2026-08-20]] §1

> [!note]- 29. WA/CWA/NA ground classes [M] — .lumen's Live Map layer 3
> **What**: walkable / conditionally-walkable / non-walkable ground
> segmentation from down-ToF + camera, richer than binary obstacle.
> **Source**: [[patents-stripmine-2026-08-20]]

> [!note]- 30. Complexity-scaled cue intensity [M]
> **What**: haptic/audio intensity driven by corridor width + upcoming
> turn angle (from the ToF walkable estimate), not just obstacle
> distance. .lumen's path-complexity score.
> **Source**: [[patents-stripmine-2026-08-20]]

> [!note]- 31. Panic/fallback button [S]
> **What**: one dedicated input → all guidance stops, calm orientation
> mode. (Glide ships one.)
> **Source**: [[patents-stripmine-2026-08-20]]

> [!note]- 32. Scan-coaching + yield-to-user-clicks [M each]
> **What**: (a) tick as obstacle edges cross center during a deliberate
> head sweep (O&M scanning training); (b) mic detects the user's own
> echolocation click → device goes quiet (published nowhere — novelty).
> Note: click-yielding matters less now the 2–5 kHz ban is lifted.
> **Source**: [[biosonar-2026-08-20]]

> [!note]- 33. VAD conversation gate [M]
> **What**: laptop mic + voice-activity detection → suppress routine
> callouts while you're talking with someone.
> **Source**: [[blv-daily-life-2026-08-18]]

> [!note]- 34. B1 sync pin — interleave the two ToF windows [S]
> **What**: 1 wire + 1 API call (`set_external_sync_pin_enable`,
> L8CX-only) kills mutual interference between sensors A and B.
> **Source**: [[ultrasonic-mmwave-glass-2026-08-20]] (found in our own driver)

> [!note]- 35. Hydrophobic cover coating + brim [S] — $5 rain fix
> **What**: the ToF's real rain failure is water ON the cover glass.
> (GuideTouch's spinning-cover alternative works but is 70 dB.)
> **Source**: [[ultrasonic-mmwave-glass-2026-08-20]], [[guidetouch-2026-08-20]]

> [!note]- 36. Ultrasonic ranger add-on [M] — the glass backstop
> **What**: TDK CH201 or MaxBotix (~$35) on the existing I2C bus;
> 99.99% acoustic reflection off glass vs our 4%; covers matte-black +
> sunlight too. Disagreement with ToF = material detector.
> **Source**: [[ultrasonic-mmwave-glass-2026-08-20]]

> [!note]- 37. IR LED illuminator [M] — camera night vision
> **What**: cheap IR floods let the camera see in darkness (.lumen
> ships IR projectors; our ToF already works in the dark — only the
> camera goes blind).
> **Source**: [[QA-2026-08-20-part2]] §2

> [!note]- 38. Foveated ROI processing [S-M]
> **What**: full-frame low-res + full-res crop where ToF says something
> is closing. 5–10× compute saving in an afternoon.
> **Source**: cv-stack research 2026-08-16

> [!note]- 39. Barometer for floor changes [S-M]
> **What**: BMP390 (~$3, I2C) detects elevator/stair floor transitions
> at 75–97% accuracy.
> **Source**: [[imu-uses-2026-08-17]]

> [!note]- 40. Ground-plane bbox ranging + head-as-gimbal memory + step-counter odometry [M each]
> **What**: (a) range camera-only detections from geometry (d =
> h/tan(pitch+θ)) beyond ToF reach; (b) 2–5 s obstacle memory ("pole
> still on your right") — unpublished framing; (c) "about 30 m since
> the doorway" from step counting (~1% error head-worn).
> **Source**: [[imu-uses-2026-08-17]]

> [!note]- 41. Fall detection + stumble ground-truth logging [M / S]
> **What**: head-worn fall detection is validated at 97% — needs a
> phone alert path to matter; every stumble auto-labels a missed-alert
> (feeds idea 16).
> **Source**: [[imu-uses-2026-08-17]]

> [!note]- 42. Camera↔ToF de-rotation + firmware timestamps [M]
> **What**: during fast head scans the 67 ms ToF latency misregisters
> zones by up to 1.4 m at 3 m; IMU de-rotation + timestamps fix it.
> **Source**: [[imu-uses-2026-08-17]]

> [!note]- 43. Miniguide-style range presets [S]
> **What**: user-settable caution range (0.5/1/2/4 m) — shipped and
> liked in the Miniguide; context-dependent needs.
> **Source**: [[blv-daily-life-2026-08-18]]

> [!note]- 44. NaviLens code reading [M] — opportunistic only
> **What**: read ddtag markers where transit systems installed them
> (30 m vendor-claimed). None in Vancouver — never a dependency.
> **Source**: [[transit-gtfs-navilens-2026-08-20]]

> [!note]- 45. Vertical ToF splay experiment [M]
> **What**: GuideTouch pitches its two sensors 30° apart for 90°
> VERTICAL coverage (knee→head at 50 cm standoff). A re-aim experiment
> or third sensor could serve head-clearance + drop-off together.
> **Source**: [[guidetouch-2026-08-20]]

> [!note]- 46. Rideshare "is this my car" scorer [M-L]
> **What**: 1:1 verification vs the app's plate/make/colour; plate ≥5/7
> chars = decisive; fail-closed ("likely your ride, unconfirmed — ask
> the driver"). BC plates are rear-only ⇒ post-stop confirmation only.
> Go/no-go blocker: getting trip data out of the Uber app.
> **Source**: [[implementation-guide-2026-08-20]] §3b

> [!note]- 47. Gyro-drift test with motors running [S] — publishable micro-result
> **What**: no published BNO085 drift data under vibration-motor load;
> 20 minutes of logging = a citable plot for the writeup.
> **Source**: [[imu-uses-2026-08-17]]

> [!note]- 48. 4K camera swap (same mount, not a second camera) [S-M hardware]
> **What**: 9× pixel area (32 px/deg) makes keys/cards findable and
> extends OCR range ~3×. Distinct from the REJECTED second boresighted
> camera — this replaces the existing one. Global-shutter option
> (OV9281-class) also kills motion blur.
> **Source**: [[feasibility-pack-2026-08-20]], [[implementation-guide-2026-08-20]]

> [!note]- 49. Platform/process: Rerun embed · Pi 5+Hailo untethered build · 90-s demo video · fisheye detector fine-tune · FP/hour metric · expert conversations (UBC O&M, GTT)
> **What**: portfolio-impact items — scrubbing a real walk in-browser
> (biped used Rerun); TRL upgrade to untethered; the demo shot-list is
> already locked; publish false-positives-per-hour as a first-class
> metric (WeWALK died by false positives).
> **Source**: [[portfolio-impact-2026-08-17]]

> [!note]- 50. Zenodo DOI — waiting on YOUR 3-minute GitHub toggle
> **What**: disclosure is already live (GitHub release v1.0-disclosure).
> zenodo.org → Log in with GitHub → Account → GitHub → flip
> `vl53l8cx-pointcloud-esp32` → tell me → I cut a release and the DOI
> mints automatically.
> **Source**: [[DEFENSIVE-PUBLICATION]]

> [!note]- 51. Text-noticed earcon [S-M] — solves "when do we read signs"
> **What**: cheap text DETECTION runs continuously; when salient text
> appears (big, centered, stable ~1 s) a tiny chirp says "readable text
> here" — you pull the actual READ with a command. 60 s cooldown per
> region. Reading itself is always on-demand ("read what's in my hand").
> **Source**: [[QA-2026-08-22]] §2

> [!note]- 53. ✅ "What's in my hand" — VLM description on demand [M] — **research done, build-ready**
> **What**: keypress → one concise spoken sentence about the live frame
> ("what's in my hand" / "what's ahead"). Query tier only; safety audio
> always preempts.
> **The design (researched 2026-08-22)**: Qwen3-VL-8B local via Ollama
> (6 GB, ~2 s) + Claude API fallback; sharpest-of-10-frames selection;
> bottom-center crop for hand mode; sensor-fusion prompting (YOLO+ToF
> state injected as text) to kill hallucination; **forced abstention**
> — BLV users can't detect wrong answers, so "I can't see that" beats a
> guess. WorldScribe (UIST 2024) validated the exact cascade we'd have.
> **Source**: [[vlm-integration-2026-08-22]]

> [!note]- 52. Event-driven detector scheduling [S-M] — your FPS insight
> **What**: YOLO at 2–3 fps idle; boost to full rate when ToF sees
> something new/closing, the beacon is guiding, or a query fires.
> Speech is event-driven anyway — constant full-rate CV is waste. Pairs
> with foveated ROI (#38); key for the untethered build.
> **Source**: [[QA-2026-08-22]] §4

---

## ⚖ Open questions (your call, no default)

> [!question]- Facial recognition
> You lean "not necessarily useful"; no longer privacy-blocked by your
> ruling. Research: users' own verdict was negative; third-party harm
> documented in the docs for whenever this goes public. Sitting until
> you decide.

> [!question]- Empty seat: auto-pick vs "describe the seating"
> See idea 11 — both buildable; the reframe converts the socially
> costly false positive into honest information.

---

## ✅ Already built & shipped (no decision needed)

> [!success]- The shipped stack (expand for the full list)
> Silence-default callout engine (60 s cooldowns, stale-drop, approach
> re-announce) · TTC terminal-buzz ticker + range-adaptive path cone ·
> two-item grammar, hedging, no numbers walking · cane-blind-spot
> filter · person deprioritized · F8 hush / F9 query · brevity mode +
> trainer · directive commands · voice-guided leveling · motor ID over
> WiFi · software+hardware mute · **Soundscape beacon (key g)** ·
> **IMU mount calibration** · sensors-lost callout · Glide-style
> stop-don't-push behavior partially via directive tier.

---

## ❌ Rejected — with reasons (don't re-litigate without new evidence)

> [!failure]- Second boresighted narrow camera — YOUR ruling 2026-08-21
> Consequence accepted: no text at range (bus headsigns out), last-metre
> uses fisheye centre + ToF. The 4K SWAP (idea 48) remains available.

> [!failure]- Wired/DIY bone conduction install — YOUR ruling 2026-08-21
> Bluetooth BC accepted instead (speech + mono ticker + coarse beacon
> all tolerate BT latency). Wired AMCaoYiLi pair purchased $33.90 for
> September precision work; DIY transducer bonding dropped.

> [!failure]- Terrain narration — reopened by you, then closed by evidence
> ToF range collapses to ~1 m in sunlight = sees no farther than the
> cane sweeps; black ice is a material problem our sensor can't touch;
> hikers' revealed preference is poles/dog/buddy; IMU classification is
> reactive (feet do it free). Survivor: drop-off detection (idea 14) +
> the upward sensor as the real trail story.

> [!failure]- Currency detection — reopened by you, then closed by evidence
> Free apps (Cash Reader, Seeing AI) + 117k free BEP readers own it;
> CAD/EUR/GBP identifiable by touch; head camera makes framing WORSE
> than a phone. Demo-only at best.

> [!failure]- "Find me an empty seat" (naive auto-pick)
> Backpack/handbag are COCO's two worst classes; a false positive =
> public humiliation = abandonment. Reframed as idea 11.

> [!failure]- Open-space person-following
> Wrong identity ~20% of trajectory time (IDF1 75–80) on EASY
> benchmarks; from behind in coats ≈ coin flip; the elbow beats it
> walking; a UWB tag beats vision. Narrowed to idea 24.

> [!failure]- Go/no-go crossing calls
> The one error that kills; ACB/NFB positions agree. Alignment only.

> [!failure]- Faces/emotions/standalone pedestrian callouts
> Users explicitly reject person-callouts ("people move"); people stay
> as INPUTS to queue/follow/collision features. Face ID: see open
> questions.

> [!failure]- Full indoor SLAM / venue mapping
> GoodMaps' lane; needs infrastructure or beacons; our moat is
> perception, not mapping.

> [!failure]- PDR breadcrumb return-path
> 9 m error from one head turn — heads lead turns; killed by physics.
> (Teach-and-repeat, idea 23, is the viable cousin.)

> [!failure]- Continuous rich sonification (vOICe-style)
> 73 h training, zero adoption in 30 years.

> [!failure]- Loudness = distance
> Bats actively remove the cue; blind users are poor at absolute
> loudness. Volume = confidence only.

> [!failure]- Event cameras / cheap radar now / stochastic-resonance haptics
> Quote-only pricing + no pretrained detectors; zero azimuth + sees
> through walls; wrong physiological regime (our motors are
> supra-threshold).

> [!failure]- .lumen's continuous 100 Hz haptic "reins"
> Defensible alternative but conflicts with our silence-default
> evidence base; A/B someday, don't drift into it silently.

> [!failure]- Persistent recording / scene memory as a user feature
> Privacy blast radius with no demand study. (Engineering telemetry,
> idea 16, is different: local, for training.)

---

## Standing rules (your rulings, quick reference)

Privacy/regulatory ≠ a constraint this phase · compute ≠ a constraint
(GPU now, Jetson-class later) · the cane is always alongside · haptic
patterns ≤2 motors · echolocation-band ban VOIDED (sparse sounds still
required — the band carries speech/traffic) · head-clearance = 10–15 cm
above the top ToF ray, gravity-framed · prototype freely, mine every
patent, review only before selling.

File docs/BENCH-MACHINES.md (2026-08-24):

# Machine benchmarks (field-laptop shootout)

Run with `camera/bench_machine.py` — same YOLO-World model + door prompts
as live door mode, 20 timed runs, median/p90.

## Verdict (2026-08-24)

| | Lenovo (gaming) | Reubens-Laptop (Zenbook) |
|---|---|---|
| CPU | i7-9750H (2019, AVX2) | i5-1135G7 (2020, AVX-512) |
| RAM | 32 GB | 7.7 GB |
| GPU | GTX 1650 4GB (CUDA present, **unused** — torch is CPU-only) | Iris Xe (no CUDA) |
| YOLO-World median | 170.5 ms | **104.4 ms** |
| YOLO-World p90 | 381.2 ms | **109.6 ms** |
| JPEG encode | 6.78 ms | 5.29 ms |
| Camera open (HBV) | 1204 ms | not attached at bench time |

The Zenbook wins the CPU-vs-CPU race — Tiger Lake's AVX-512 beats the
older i7, and its timings are far more consistent (p90 within 5% of
median vs 2.2× on the Lenovo, which was also running a full desktop
session). Neither machine has ever run YOLO on GPU: torch is
`2.13.0+cpu` on both. (The GTX 1650 was only exercised in the local-VLM
experiment, which it failed at 20-25 s/answer.)

**Is the Zenbook fast enough?** Yes. The safety loop (ToF → haptics →
"stop stop") does no neural inference — it's geometry at sensor rate,
identical on both machines. YOLO's 104 ms only gates on-demand door/find
scans (~1 s wall including capture), and VLM/OCR are NIM cloud calls,
identical everywhere. The Zenbook's real constraint is 7.7 GB RAM: run
Iris alone, keep browsers closed.

**Optional upgrade:** CUDA torch on the Lenovo should put YOLO-World-S
at ~20-30 ms — worth it only if scan latency ever feels slow in use.

## Lenovo — 2026-08-24 12:02

```json
{
  "host": "Lenovo",
  "os": "Windows-11-10.0.26200-SP0",
  "python": "3.12.10",
  "cpu": "Intel(R) Core(TM) i7-9750H CPU @ 2.60GHz",
  "ram_gb": 31.9,
  "gpu": "Intel(R) UHD Graphics 630 | NVIDIA GeForce GTX 1650",
  "torch": "2.13.0+cpu",
  "cuda": "none",
  "yolo_med_ms": 170.5,
  "yolo_p90_ms": 381.2,
  "jpeg_ms": 6.78,
  "cameras": {
    "Integrated Camera": 1478,
    "HBV HD CAMERA": 1204
  }
}
```

## Reubens-Laptop — 2026-08-24 12:04

```json
{
  "host": "Reubens-Laptop",
  "os": "Windows-11-10.0.26200-SP0",
  "python": "3.12.10",
  "cpu": "11th Gen Intel(R) Core(TM) i5-1135G7 @ 2.40GHz",
  "ram_gb": 7.7,
  "gpu": "Intel(R) Iris(R) Xe Graphics",
  "torch": "2.13.0+cpu",
  "cuda": "none",
  "yolo_med_ms": 104.4,
  "yolo_p90_ms": 109.6,
  "jpeg_ms": 5.29,
  "cameras": {
    "USB2.0 HD UVC WebCam": 627,
    "OBS Virtual Camera": "FAIL"
  }
}
```

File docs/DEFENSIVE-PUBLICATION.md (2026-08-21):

# An Assistive Helmet from Two $6 Depth Sensors: Calibration, Fusion, and a Silence-Default Interface

**Reuben Lavin — public technical disclosure, 2026-08-20**
Repository: https://github.com/reubenlavin08/vl53l8cx-pointcloud-esp32 (MIT)
Full engineering log: `docs/DEVLOG.md` · Research corpus: `docs/research-sources/`

## Purpose of this document

This is a **defensive publication**: a dated, public, citable disclosure
of the methods below, placed in the open specifically so that they remain
free for anyone to use. This work is an **efficient implementation of
known techniques on a $6 sensor and an ESP32** — the individual
techniques have rich prior art (cited inline); what is disclosed here is
the specific working combination, its calibration method, and its
measured constants.

## 1. System

Head-mounted assistive device for blind and low-vision users:

- 2× ST VL53L8CX 8×8 multizone time-of-flight sensors (yawed ±22.5°,
  group-pitched 22.5° down, seam-abutted for a ~90°×45° field), on two
  independent I2C buses of an ESP32-S3; 15 Hz.
- BNO085 IMU (0x4A, shared bus, ~100 Hz), run **magnetometer-free**
  (game rotation vector) because the temple vibration motors corrupt
  the magnetic field; only orientation deltas are consumed.
- Fisheye USB camera (measured 119.58°×63.12°), calibrated with the
  OpenCV fisheye model; YOLO-class segmentation + ByteTrack on a host
  computer; mask-based (not box-based) association of depth zones to
  detections.
- 3 temple/forehead vibration motors (2N3904 low-side drive); wired
  bone-conduction audio; physical mute switch.
- All streaming over serial or TCP; OTA firmware update.

## 2. Calibration methods disclosed

**2.1 Signal-weighted zone centroids ("effective field").** A multizone
ToF zone's reported range on extended surfaces does not correspond to
the zone's geometric center ray: VCSEL illumination roll-off (field of
illumination ~43.4° at 75%) pulls each zone's effective centroid inward.
We measure a per-zone **effective direction table** from planar-target
poses and use it for metric projection, while retaining the geometric
45° field for detection-bounds reasoning. On our units the effective
centroid field is ≈34°. This resolved a persistent 8 mm planarity
residual. Prior art in spirit: lidar self-calibration (Glennie & Lichti,
2010); what is disclosed is its application to consumer multizone
SPAD sensors with per-zone effective-ray tables.

**2.2 Joint rigid two-sensor solve.** Both sensors' extrinsics are
solved jointly with the CAD-known inter-sensor transform (45.000°,
36.249 mm) enforced as a rigid constraint and one shared effective
table; result 5.51 mm rms against planar truth, 1.15° from CAD.

**2.3 Perpendicular-range correction.** VL53L8CX reports perpendicular
(not radial) distance; forward range used for alerting is
`z·cos(α+pitch)/cos(α)` per zone elevation α and mount pitch.

**2.4 IMU mount calibration.** Two-pose gravity alignment plus cardinal
snap; motors-on gyro behavior verified separately.
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

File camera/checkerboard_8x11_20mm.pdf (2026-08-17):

PRINT AT 100% / "ACTUAL SIZE" - do NOT scale to fit

0 | 100 mm

<- this must measure exactly 100 mm with a real ruler

Glue to rigid flat board (foam-core / clipboard). Flatness matters more than print quality. Matte paper only - glossy paper reflects and the corner detector fails.

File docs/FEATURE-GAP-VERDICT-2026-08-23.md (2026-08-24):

# Feature-gap verdict — full research sweep, 4 agents — 2026-08-23

You asked: anything researched-but-unbuilt that adds real value? Four
agents read the entire corpus + IDEA-BANK against the built stack.
**Verdict: the gap is interaction depth + two flagships + measurement —
NOT more detectors.** And nothing new should start before the built
stack gets its first live test.

## Where multiple agents converged (the signal)

| Feature | Agents | Effort | Why |
|---|---|---|---|
| **Tap-to-query** (double-tap shell → VLM describes) | 2 | **S (3-5 h)** | THE demo surprise: unused on-chip silicon + built pipeline, one gesture, no hands. Also the silent-in-public path the voice research demanded |
| **Find-by-text + sign read (one OCR engine)** | 2 | M | Text = the #1-ranked BLV need; nemotron benchmarked (1.3–2.4 s, per-word boxes → beacon comes free); highest reuse of built machinery; wow 5. Headline find-by-text; label-read ships quietly (commoditized) |
| **Around-Me quadrants + "tell me more" layers** | 2 | S-M | The #1 requested interaction property in BLV studies; upgrades F9+VLM+voice at once — demo becomes a conversation |
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

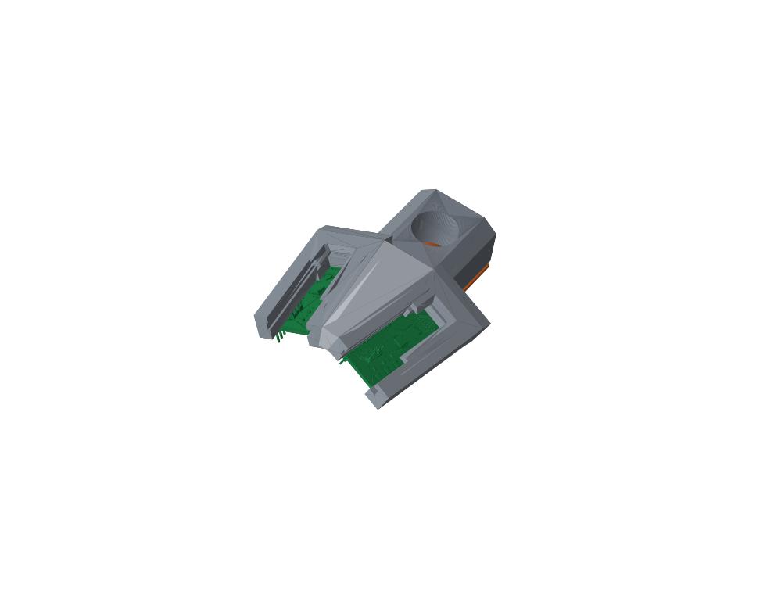
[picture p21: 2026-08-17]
cad/render/explode_001.png

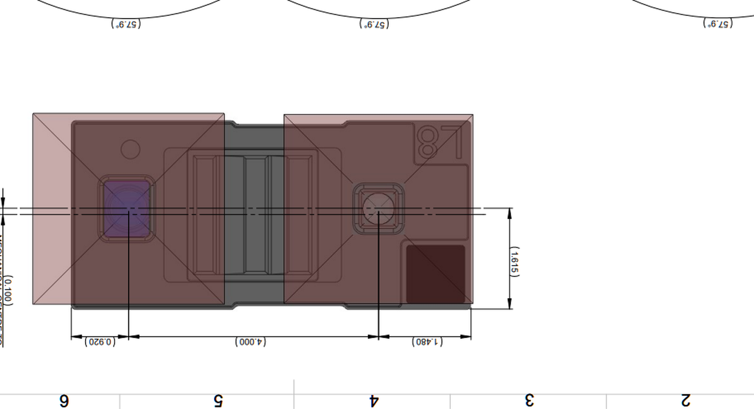
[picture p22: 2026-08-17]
docs/datasheets/tof/fig26-28-outline/fig28_topfull.png

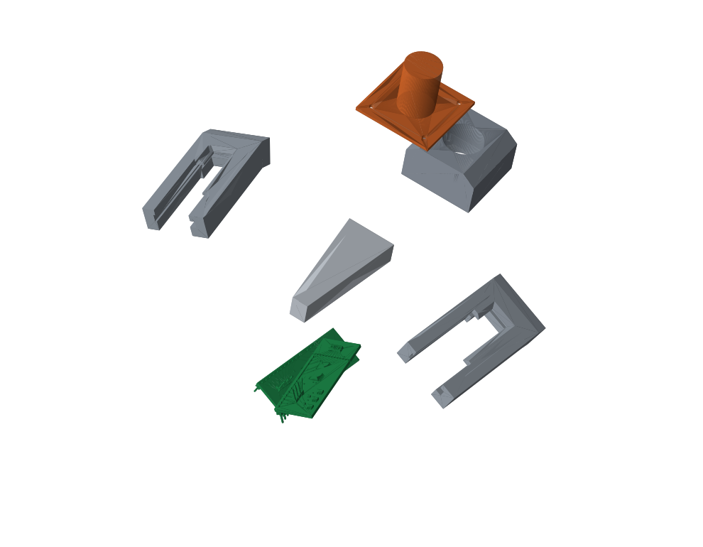
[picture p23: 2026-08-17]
cad/render/explode_046.png

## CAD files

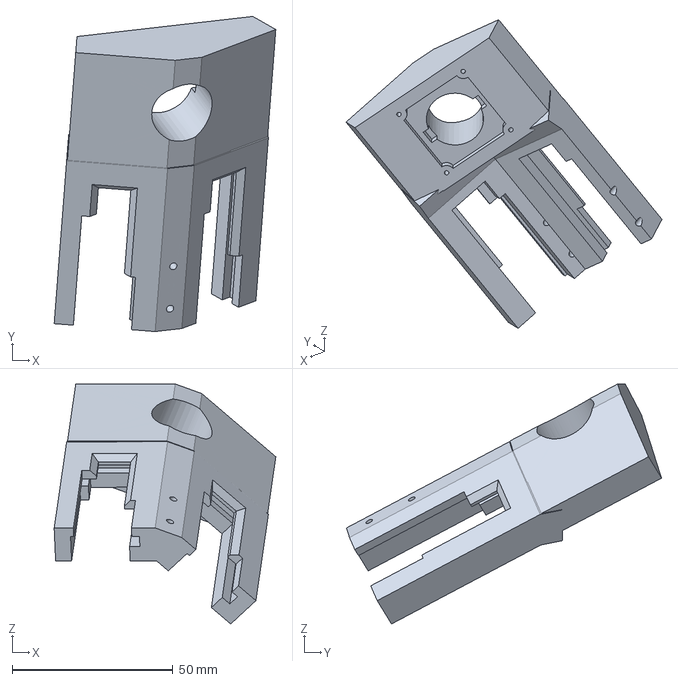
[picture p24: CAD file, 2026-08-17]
cad/solidworks/upper_sensor_pod.3MF
69.0 x 98.0 x 74.7 mm

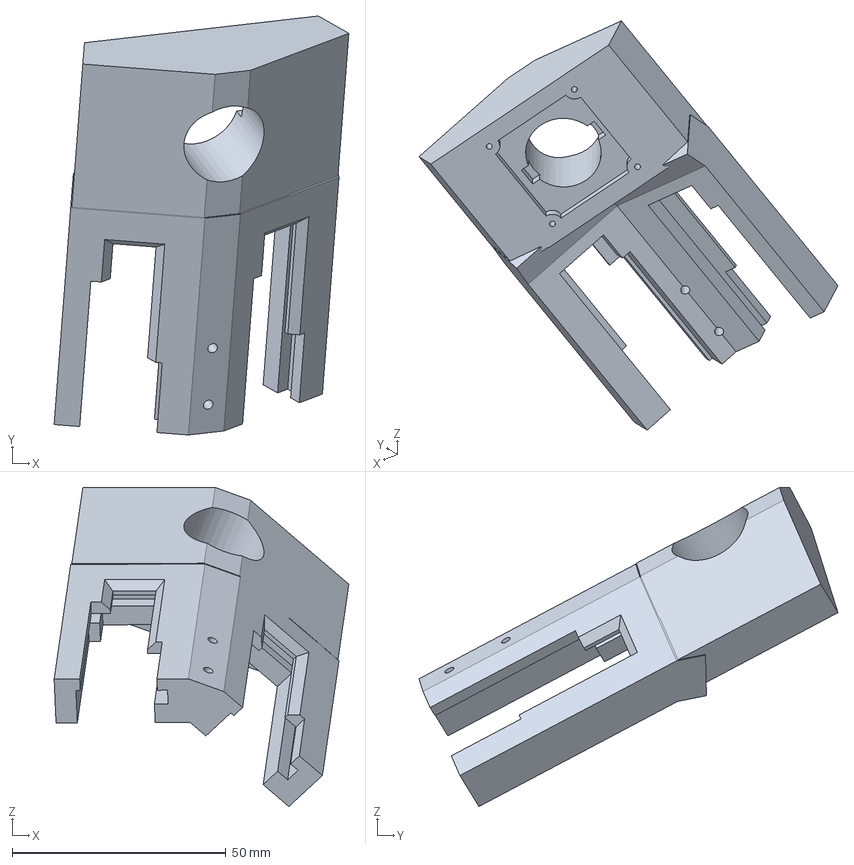
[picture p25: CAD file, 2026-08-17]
cad/solidworks/pod_upper_casing_prt_cmbd.3MF
69.0 x 98.0 x 74.7 mm

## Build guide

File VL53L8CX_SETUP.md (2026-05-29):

# VL53L8CX × ESP32 — Setup Summary

> **Note (2026-05-28):** This doc is a **fresh-machine quickstart**. The project has moved well past the initial setup it describes — current production firmware runs at **4×4 / 30 Hz** (not 8×8 / 10 Hz), with WiFi streaming, OTA updates, body-frame rotation, per-row slant compensation, a buzzer alert, and a 3-motor directional haptic ring. For everything past first-boot, see [`README.md`](README.md) (v7 onward) and [`PROGRESS.md`](PROGRESS.md) (v1–v6).

## Completed Tasks

- [x] Located the RJRP44 VL53L8CX ESP-IDF library (v4.0.0) on the ESP Component Registry
- [x] Created ESP-IDF project structure (`CMakeLists.txt`, `sdkconfig.defaults`)
- [x] Wrote `idf_component.yml` to auto-fetch the library on build
- [x] Wrote `main.c` — full sensor interface with I2C init, ULD firmware upload, 8×8 ranging loop, and ASCII distance grid output
- [x] Pre-configured stack size fix in `sdkconfig.defaults` (8192 bytes)

---

## Project File Structure

```
vl53l8cx_esp32/
├── CMakeLists.txt
├── sdkconfig.defaults
└── main/
    ├── CMakeLists.txt
    ├── idf_component.yml
    └── main.c
```

---

## Wiring Chart — SATEL-VL53L8CX Breakout → ESP32

| SATEL Pin | ESP32 Pin | Notes |
|---|---|---|
| PWREN | GPIO 5 | + 10 kΩ pullup resistor to 3.3V  |
| MCLK_SCL | GPIO 2 | + 2.2 kΩ pullup resistor to 3.3V |
| MOSI_SDA | GPIO 1 | + 2.2 kΩ pullup resistor to 3.3V |
| NCS | 3.3V | Tie directly high (I2C mode) |
| SPI_I2C_N | GND | Tie directly to GND (I2C select) |
| VDD | 5V | Power supply |
| GND | GND | Common ground |

> **Note:** The external pullup resistors are required — do not rely on ESP32 internal pullups for this sensor.

---

## Computer Setup Steps

### Step 1 — Install ESP-IDF (v5.0 or later)

1. Download the ESP-IDF installer for Windows from:  
   https://dl.espressif.com/dl/esp-idf/
2. Run the installer and follow the prompts (installs Python, CMake, Ninja, and the toolchain automatically)
3. After install, open the **ESP-IDF Command Prompt** (added to your Start Menu) — use this terminal for all commands below

Verify your install:
```bash
idf.py --version
```
Expected output: `ESP-IDF v5.x.x`

---

### Step 2 — Install the USB-to-Serial Driver

Most ESP32 dev boards use a CP2102 or CH340 USB chip. Install the correct driver:

- **CP2102** (common on Espressif devkits): https://www.silabs.com/developers/usb-to-uart-bridge-vcp-drivers
- **CH340** (common on cheap clones): https://www.wch-ic.com/downloads/CH341SER_EXE.html

After installing, plug in your ESP32. Open **Device Manager** (`Win + X → Device Manager`) and confirm it shows up under **Ports (COM & LPT)** — note the COM number (e.g., `COM5`).

---

### Step 3 — Copy the Project to Your Machine

Copy the `vl53l8cx_esp32/` folder anywhere on your computer, for example:
```
C:\Projects\vl53l8cx_esp32\
```

---

### Step 4 — Open the ESP-IDF Command Prompt and Navigate to the Project

```bash
cd C:\Projects\vl53l8cx_esp32
```

---

### Step 5 — Set Your ESP32 Target Chip

Run the command matching your specific board:

```bash
# Standard ESP32
idf.py set-target esp32

# ESP32-S3
idf.py set-target esp32s3

# ESP32-C3
idf.py set-target esp32c3
```

---

### Step 6 — Pull the VL53L8CX Library

The `idf_component.yml` file handles this automatically on first build, but you can also run it manually:

```bash
idf.py add-dependency "rjrp44/vl53l8cx^4.0.0"
```

---

### Step 7 — Adjust GPIO Pins (if needed)

Open `main/main.c` and update these three lines at the top to match your actual wiring:

```c
#define GPIO_SDA    GPIO_NUM_1   // MOSI_SDA pin
#define GPIO_SCL    GPIO_NUM_2   // MCLK_SCL pin
#define GPIO_PWREN  GPIO_NUM_5   // PWREN pin
```

---

### Step 8 — Build the Project

```bash
idf.py build
```

The first build downloads the library and uploads ST's ULD firmware blob — this takes 1–3 minutes. Subsequent builds are much faster.

---

### Step 9 — Flash and Monitor

Replace `COM5` with your actual COM port number from Step 2:

```bash
idf.py -p COM5 flash monitor
```

The serial monitor opens automatically after flashing. You should see:

```
I (xxx) VL53L8CX: Sensor detected
I (xxx) VL53L8CX: Uploading ULD firmware (takes ~1 s)...
I (xxx) VL53L8CX: Configured: 4x4, 30 Hz, sharpener=5%, order=CLOSEST, filter={5,6,9}
I (xxx) VL53L8CX: Ranging started
I (xxx) VL53L8CX: Frame #1

--- Distance grid (mm) ---
  820  815  801  790  785  780  775  770
  ...
```

Press **Ctrl + ]** to exit the monitor.

---

## Sensor Configuration Quick Reference

These defines in `main/main.c` control sensor behaviour:

| Define | Current default *(see note above)*  | Options |
|---|---|---|
| `SENSOR_RESOLUTION`  | `VL53L8CX_RESOLUTION_4X4` | `_8X8`. 4×4 picked after the v9 sweep — 4× lower per-zone noise, big enough for the helmet's binary-alert use case. |
| `RANGING_FREQ_HZ` | `30` | 1–15 Hz at 8×8, 1–60 Hz at 4×4. Picked 30 after wearable-latency analysis (`docs/research-optimal-config.md`). |
| `RANGING_MODE` | `VL53L8CX_RANGING_MODE_CONTINUOUS` | `_AUTONOMOUS` for low-power. |
| `PRINT_GRID` | `0` | `1` for the ASCII grid log every frame. |
| `PRINT_CLOSEST_ONLY` | `0` | `1` to only log the single nearest zone. |

For the full current configuration knob list (HAPTIC_TEST, buzzer, per-row thresholds, MOUNT_ROTATION_DEG, MOUNT_PITCH_DEG, etc.), see the "Configuration knobs" section of [`README.md`](README.md).

---

## Troubleshooting

| Symptom | Likely cause | Fix |
|---|---|---|
| `Sensor not detected` | Wiring issue or no power | Check PWREN, I2C pullups, NCS tied to 3.3V, SPI_I2C_N to GND |
| Stack overflow crash | Main stack too small | Already fixed in `sdkconfig.defaults` — rebuild after cleaning |
| `idf.py` not found | ESP-IDF not in PATH | Use the ESP-IDF Command Prompt, not a regular terminal |
| No COM port in Device Manager | Driver missing | Install CP2102 or CH340 driver (Step 2) |
| Build errors on library | IDF version too old | Must use ESP-IDF v5.0 or later |

---

## References

- [RJRP44/VL53L8CX-Library on GitHub](https://github.com/RJRP44/VL53L8CX-Library)
- [rjrp44/vl53l8cx on ESP Component Registry](https://components.espressif.com/components/rjrp44/vl53l8cx)
- [ST VL53L8CX Product Page](https://www.st.com/en/imaging-and-photonics-solutions/vl53l8cx.html)
- [ESP-IDF Programming Guide](https://docs.espressif.com/projects/esp-idf/en/latest/)

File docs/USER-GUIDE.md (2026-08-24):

# Iris user guide

Everything the system does, and every way to trigger it. Three ways to
control Iris: **voice** (wake word), **phone app** buttons, **keyboard**
on the computer viewer. Plus two gestures on the helmet itself.

## Always on (no trigger needed)

| Feature | What you experience |
|---|---|
| Obstacle callouts | "Stop stop" (<1.2 m directly ahead), "step left/right", named objects when the camera is confident ("maybe chair 2 meters"). Low confidence = just "obstacle" — a wrong name is worse than no name. |
| Haptic motors | Left/center/right temple buzzing, stronger = closer. Works even with audio muted. |
| Proximity ticker | Parking-sensor clicks that speed up as the nearest thing gets closer, panned left/right to where it is. |
| Head-turn gate | While you whip your head around, routine cautions hold their tongue (a fighter-pilot "sterile cockpit"). Urgent warnings still get through. |
| Head clearance | Warns "low clearance, duck" + double haptic pulse for head-height obstacles (branches, door frames) using the IMU to know true vertical. |
| Drop detection | If the helmet falls off, it announces where it is every 10 s and mutes hazard chatter. |
| Flight log | Everything is recorded (speech, sensor data). Last 60 s of video/sensors saved automatically around any incident. |

## Voice commands

Say **"Iris"**, wait for the **high beep**, then the command (5 s window):

- **"describe"** — AI looks through the camera and tells you what's ahead (2-6 s)
- **"what's in my hand"** — same, focused on a held object
- **"what's around"** — one item per direction (front-left / center / right). Say it again within 10 s for distances; a third time for the full AI description
- **"scan doors"** — finds up to 3 doors, tells you clock direction + steps; then **"door one/two/three"** picks one and the audio beacon guides you to it
- **"find door"** (also: window, chair, stairs, table, couch, bed, fridge, sink, elevator, garbage) — finds the *object* with open-vocabulary detection, beacon guides you to it
- **"find exit"** (also: washroom, open, push, pull, sale, ketchup) — finds that *written text* on signs/labels, locks the beacon on it. Text words need actual writing in view — a door with no EXIT sign won't match "exit"; say "find door" for that
- **"read that"** — reads nearby text aloud
- **"guide"** — audio beacon toward what's centered ahead
- **"audio on"** — unmute

**No wake word needed, anytime:** "stop", "quiet" (mute), "wrong" (that callout was wrong — logged for tuning).

## Helmet gestures

- **Double-tap the shell** — same as "describe"
- (Falling helmet announces itself — that's automatic)

## Phone app (and computer viewer buttons)

Top-to-bottom / left-to-right: **What's around · Describe · Mute · Flag ·
Rotate · Help (?) · REC · Power**. Flag = "remember this moment": saves
the last 60 s of video + sensors so problems can be replayed later.
Rotate fills a portrait phone screen with the video (hold the phone
sideways). REC records the annotated video + laptop mic to
`camera/sessions/*_rec/` — for backpack field runs ("Iris… start
recording" works too). Power (tap twice to confirm) shuts Iris down
cleanly and returns the app to the Start screen.

## Keyboard (computer viewer)

| Key | Action |
|---|---|
| `v` / `h` | Describe / what's in my hand |
| `d` then `1-3` | Door scan, pick a door |
| `f` | Find text (type the word) |
| `r` | Read that |
| `g` | Guide beacon on what's ahead |
| `n` | Walkable-tunnel haptics (corridor centering) |
| `l` | Level check (IMU) |
| `u` | Toggle steps/meters |
| `c` | Start/stop session recording (video + mic) |
| `x` | "Wrong" (false-positive vote) |
| `F8` | Mute/unmute |
| `F9` | What's around |
| `F12`/`?` | Print this help in the console |

## The one-line mental model

The helmet handles **"don't walk into things"** automatically (ToF +
haptics + short words). Everything else is **ask-and-answer**: you ask
(voice, tap, button, key), Iris answers once, then goes quiet.

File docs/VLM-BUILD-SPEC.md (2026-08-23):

# VLM describe/OCR build spec — 2026-08-23

Scoped to industry practice for a production LLM-API integration.
Research base: [[vlm-integration-2026-08-22]] (WorldScribe cascade,
abstention-first prompting, VizWiz failure modes) + live benchmarks.

## Decisions (final)

| Item | Decision | Why |
|---|---|---|
| Model | NIM cloud `meta/llama-3.2-11b-vision-instruct` | 2.3–6.4 s measured; correct abstention; local FAILED on both machines (GTX 1650 4 GB = 20–25 s; field laptop = Iris Xe iGPU, no CUDA) |
| Text/OCR | NIM `nvidia/nemotron-ocr-v2` (free endpoint) — benchmark next | scene-text specialist beats a generalist VLM at reading |
| Interaction | Pull-only keys: `v` = describe ahead, `h` = what's in my hand | silence-default; voice later |
| Connectivity | Requires network (field = phone hotspot, already the rig's design) | no local option exists |

## Industry-standard requirements (the checklist)

1. **Secrets**: API key from `NVIDIA_API_KEY` env var, falling back to a
   git-ignored local file. **Never in code, never committed.**
2. **Timeouts + retry**: connect 5 s, read 20 s; ONE retry on 5xx/timeouts;
   then a spoken, honest failure ("description unavailable — no
   connection"). Silence must never mean "nothing there."
3. **Single-flight**: one query in the air; re-press while busy →
   "still working." No queues that speak stale answers.
4. **Cancellation**: safety tier (directive speech) preempts — result of
   a cancelled query is dropped, never spoken late.
5. **Input hygiene**: sharpest-of-last-10-frames (variance of
   Laplacian); JPEG q70 (~75 KB, under NIM inline limits); hand mode =
   bottom-center crop (egocentric held objects live there).
6. **Grounding**: current YOLO+ToF detections injected as text context
   ("person 1.2 m ahead-left") + instruction not to mention unseen
   objects — the anti-hallucination measure from the research.
7. **Output discipline**: model ignores word caps → client-side
   truncate to the first 2 sentences; strip markdown/asterisks before
   TTS.
8. **Abstention prompt**: "if blurry or not visible, say so — never
   guess" (BLV users cannot detect a wrong answer; verified working in
   our benchmark).
9. **Observability**: every query logged (timestamp, latency, question,
   answer, http status) to `camera/vlm_log.jsonl` — feeds the
   intervention-logging flywheel (IDEA-BANK #16).
10. **Stale-frame guard**: frame older than 1 s → re-grab; answer tagged
    to the frame's timestamp.

## Out of scope (this build)

Voice input · streaming TTS (answers are 1–2 sentences; not worth SSE
complexity at 2–6 s total) · OCR endpoint integration (next build,
after benchmark) · continuous description (never — vOICe lesson).

## Files

- `camera/vlm.py` — client module (key loading, frame selection,
  request, retry, truncation, logging).
- `cv_fusion.py` — frame ring buffer + keys `v`/`h` + busy flag +
  query-tier speech handoff.

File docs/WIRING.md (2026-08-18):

# WIRING — verified 2026-08-11/12

Written after a full teardown/remount onto the bike helmet + 3D-printed pod, when
nobody remembered how anything was wired.

**Everything marked ✅ VERIFIED was proven on hardware this session** — both ToF
sensors were brought up from scratch on new pins and streamed live distances.

> **Trust order:** this file > the ELF/source > other docs. `docs/imu-bno085-bringup.md`
> describes an **ESP32-C6 SPI bench rig** and is NOT the current wiring — see §2.

---

# 1. ToF sensors — ✅ VERIFIED WORKING

Two SATEL-VL53L8CX, one per I²C bus. Both answered at **0x29**, uploaded ULD
firmware, and ranged.

```
[A] SDA=6  SCL=7  : 0x29    *** RANGING OK ***  PWREN=4
[B] SDA=15 SCL=16 : 0x29    *** RANGING OK ***  PWREN=5
```

## Current pin assignment (after the remount)

| | Sensor A | Sensor B |
|---|---|---|
| `MOSI_SDA` | **GPIO6** | **GPIO15** |
| `MCLK_SCL` | **GPIO7** | **GPIO16** |
| `PWREN` | **GPIO4** | **GPIO5** |
| Bus | `I2C_NUM_0` | `I2C_NUM_1` |

**SDA/SCL are NOT swapped from the silkscreen on these boards.** Tested both
orientations; the by-the-label wiring is correct.

## Every pin on the SATEL board

| Pin | Connect to | |
|---|---|---|
| **VDD** | **5V** | not 3.3 V |
| **GND** | GND | |
| **MOSI_SDA** | its SDA GPIO | + 2 kΩ → 3.3 V |
| **MCLK_SCL** | its SCL GPIO | + 2 kΩ → 3.3 V |
| **PWREN** | its PWREN GPIO | + 10 kΩ → 3.3 V |
| **NCS** | 3.3 V | tie high = I²C mode |
| **SPI_I2C_N** | GND | tie low = I²C mode |
| `MISO` | — | nothing (SPI only) |
| `LPn` | — | nothing |
| `GPIO1`, `GPIO2` *(sensor's own)* | — | nothing |
| `3V3`, `1V8 / CORE_1V8`, `IOVDD` | — | nothing (regulator outputs) |

**7 pins wired, 8 empty, per sensor.**

⚠️ **The SATEL board has its own pins named GPIO1 and GPIO2 — they are not the
ESP's.** Matching them by name gives a sensor that powers up and never answers.

## Why two buses

Both sensors are fixed at **0x29** and changing it needs `LPn` juggling. Separate
buses avoids the collision entirely.

---

# 2. BNO085 IMU — I²C, not SPI

**Settled definitively.** The flashed ELF contains `bno08x_init`, `sh2_open`,
`i2c_master_transmit` ×7, `i2c_master_receive` ×3, and **zero SPI symbols**. A
repo-wide sweep for `driver/spi_master.h`, `spi_bus_initialize`,
`spi_device_transmit`, `SPI2_HOST` matches **nothing**. There is no SPI code in
this project.

Confirmed physically: **PS1 = PS0 = GND**, which is the I²C strapping (`00`).

**SPI was real but older, and on an ESP32-C6 bench rig** — that's what
`docs/imu-bno085-bringup.md` documents. It was rewritten for I²C on the shared
bus when the IMU moved to the S3.

| BNO085 pin | Connect to | |
|---|---|---|
| VCC | 3.3 V | |
| GND | GND | |
| SDA | bottom-bus SDA | shares the bus with a ToF |
| SCL | bottom-bus SCL | |
| ADO | GND | → address **0x4A** |
| **PS1** | **GND** | ✅ verified |
| **PS0** | **GND** | ✅ verified |
| CS | 3.3 V | |
| INT | **nothing** | INT pad unreliable; driver polls (`int_gpio = -1`) |
| RST | **nothing** | |

**Address is 0x4A, not 0x4B.** 0x4B ACKs a write but never decodes SHTP.
`docs/DEVLOG.md:234` still says 0x4B and is **stale**; line 123 corrects it.

**PS1/PS0 latch only at power-on.** A soft reset or reflash won't re-read them —
fully unplug after changing straps.

**No extra pullups when adding the IMU** — it taps the existing bus pair.

⚠️ Unverified: the SDA/SCL swap DEVLOG claims for the GY-BNO08X clone. Not in the
code, so it couldn't be checked. **Try by-the-label first**; only swap if the
probe finds nothing.

---

# 3. Pull-up resistors

**6 total. All in parallel, each bridging its own signal to the same 3.3 V rail.
Nothing is in series along a bus line.**

```
              3.3 V rail
   ┌────┬────┬────┬────┬────┬────┐
 [2k]  [2k]  [2k]  [2k] [10k] [10k]
   │     │     │     │    │     │
  SDA   SCL   SDA   SCL  PWREN PWREN
  └── bus A ──┘└── bus B ┘
```

| Lines | Value |
|---|---|
| All four SDA/SCL | **2 kΩ** |
| Both PWREN | **10 kΩ** |

## The 2 kΩ are built from 1 kΩ pairs in SERIES

Series **adds**: 1k + 1k = 2 kΩ ✅
Parallel **halves**: 1k ∥ 1k = 500 Ω ❌ — 4× too strong, bus won't reach a valid low.

**Check with a meter across a finished pair: ~2 kΩ good, ~500 Ω rewire.**

2 kΩ instead of the nominal 2.2 kΩ is fine — 10% off in the helpful direction,
1.65 mA per line.

## A pullup attaches to the NET, not to a component

The GPIO and the sensor pin are one piece of copper, so the resistor can sit at
either end or in the middle — electrically identical. There is no single
correct-looking physical arrangement.

**One pair per BUS, not per device.** The bus shared with the IMU still gets only
one 2 kΩ pair.

## Colour codes

| Value | 4-band | 5-band |
|---|---|---|
| **1 kΩ** | brown black red gold | brown black black brown brown |
| **2.2 kΩ** | red red red gold | red red black brown brown |
| **10 kΩ** | brown black **orange** gold | brown black black **red** brown |

⚠️ Band 4 red-vs-brown is the classic misread and is the only difference between
1 kΩ and 10 kΩ in 5-band. **Measure, don't read.**

---

# 4. PWREN

**Active-high enable.** `platform.c:74-85` with `CONFIG_VL53L8CX_RESET_PIN_LOW=y`
(`sdkconfig:2174`):

```c
gpio_set_direction(reset_gpio, GPIO_MODE_OUTPUT);
gpio_set_level(reset_gpio, 0);   // 100 ms — held in reset
gpio_set_level(reset_gpio, 1);   // 100 ms — enabled
```

| PWREN | Sensor |
|---|---|
| LOW | held in reset, invisible on the bus |
| HIGH | running |

**Why the 10 kΩ if the ESP drives it:** from power-on until the firmware runs the
GPIO is a floating input and PWREN would be undefined. The pullup holds the
sensor enabled through boot. Once the pin becomes push-pull it overrides 10 kΩ
easily — they never fight.

**Don't tie PWREN straight to 3.3 V** — the ESP must be able to pull it low.

**A sensor with floating or low PWREN looks exactly like a broken SDA line.**
Check it first.

---

# 5. Power rails

| Rail | Feeds |
|---|---|
| **5 V** | both ToF `VDD` |
| **3.3 V** | both ToF `NCS` · BNO085 `VCC` + `CS` · **all 6 pullups** |
| **GND** | both ToF `SPI_I2C_N` · BNO085 `ADO`, `PS1`, `PS0` · switch outer leg · common |

## ⚠️ Every pullup goes to 3.3 V, never 5 V

ESP32-S3 GPIOs are **not 5 V tolerant** (abs max ~3.6 V). A pullup on the 5 V
rail feeds 5 V into the GPIO through 2 kΩ — damages the pin, and it can half-work
first.

## ⚠️ The right-side native USB port does not power 5 V properly

**This cost a full debug cycle on 2026-08-11.** Both sensors were invisible on
both buses — every scan came back empty — purely because they had no power.

**Use the left-side UART USB port**, or supply 5 V another way.

**Symptom to recognise:** *both* buses scanning empty at once. Two independently
wired sensors failing identically points at something **shared** — power, ground,
or the 3.3 V rail — never at the data pins.

---

# 6. Other ESP32-S3 connections

| Pin | Connected to | |
|---|---|---|
| GPIO6 | *(now ToF A SDA)* | **was buzzer** |
| GPIO7 | *(now ToF A SCL)* | **was haptic CENTER / forehead** |
| GPIO15 | *(now ToF B SDA)* | **was haptic RIGHT temple** |
| GPIO16 | *(now ToF B SCL)* | **was haptic LEFT temple** |
| GPIO17 | Pause switch, SPDT common | internal pull-up; HIGH = on, LOW = paused |

Pause switch: COM → GPIO17, **one** outer leg → GND, third leg unconnected.

⚠️ **Unrecorded:** whether the three motors are driven directly or through
transistors, and whether there are flyback diodes. An S3 pin sources ~40 mA; a
coin ERM pulls 60–100 mA at start, so direct drive would be out of spec. **Check
the physical build before reconnecting them.**

---

# 7. ⚠️ FIRMWARE DOES NOT MATCH THIS WIRING YET

`main/main.c` still has the **pre-teardown** pins:

| | Firmware expects | Actually wired |
|---|---|---|
| Sensor A | SDA 1, SCL 2, PWREN 5 | **SDA 6, SCL 7, PWREN 4** |
| Sensor B | SDA 41, SCL 42, PWREN 40 | **SDA 15, SCL 16, PWREN 5** |

**And the ToF sensors now occupy the buzzer + all three haptic pins** (`main.c:57,
80-82`). Both subsystems cannot coexist on this wiring.

**Clean swap available:** GPIO1, 2, 41, 42 are now free — move the buzzer and
three motors there, and update the ToF defines at `main.c:50-56`.

Also stale: the code calls the sensors "top" (~5° up) and "bottom" (~30° down),
the **old stacked** arrangement. The CAD pod is now a **left/right ±22.5° pair**,
so `MOUNT_PITCH_DEG` and the per-column haptic mapping are both wrong for the
current geometry.

---

# 8. Test tool — `tof_pin_test/`

Standalone ESP-IDF project. **Does not touch the helmet firmware.** Reuses the
already-downloaded driver via `EXTRA_COMPONENT_DIRS`, so it builds offline.

- Loops forever, retrying every 3 s — **rewire live and watch it come up**
- Tries **both SDA/SCL orientations** on each bus and reports which won
- Full 0x08–0x77 address scan per bus
- Per-sensor failure — one bad sensor doesn't hide the other
  *(the helmet firmware `vTaskDelete`s the whole ranging task on any failure,
  which is why it can't tell you which sensor is bad)*
- Streams a 4×4 grid; `----` = no valid target

```
cd C:\esp-projects\vl53l8cx_esp32\tof_pin_test
idf.py -p COM9 flash monitor
```

Edit the pin defines at the top of `main/main.c` when the wiring moves.

## ⚠️ Native USB port: stuck in download mode

Software reset via DTR/RTS on the USB-Serial-JTAG port repeatedly landed the chip
in `boot:0x21 (DOWNLOAD)` — "waiting for download", app never runs, port silent.

**Fix: physically unplug and replug the USB cable.** A real power cycle is the
only thing that reliably clears it. Don't hand-roll DTR/RTS toggling on this port;
use `idf.py monitor` or a replug.

---

# 9. Bring-up order

Wire and verify **one device at a time**. A sensor init failure kills the whole
ranging task, so wiring everything at once means a single fault silences all of it.

1. **Sensor A alone** → boot, expect `0x29` + `RANGING OK`
2. **Sensor B** → same
3. **IMU** on the shared bus → power-cycle → `ACK at 0x4A` + `ready on bottom bus`
4. Haptics, buzzer, switch last

---

# 10. Open / unverified

1. **`VDD` vs a separate `5V` pin** on the SATEL carrier — which one is fed
2. **Full carrier board vs the break-off mini-PCB.** `docs/SENSOR-MOUNTING-FACTS.md:29`
   says the 12-pad mini-PCB has **no PWREN** — its pads are `AVDD, IOVDD, GPIO2,
   GPIO1, SCL, I2C_N, SDA, MISO, LPn, CORE_1V8, NCS, DUT_GND`. If the pod holds
   the mini-PCB, §1 is wrong: feed AVDD + IOVDD directly instead of 5 V.
3. **Motor drive circuit** — transistors? flyback diodes?
4. **BNO085 SDA/SCL swap** — DEVLOG claims it; unverified
5. **Zone dropout** — 3–5 of 16 zones per frame read `----`. Plausible for far or
   dark targets; if it persists against a close wall, revisit the pullups.
6. **Three uncommitted files** — `main/main.c`, `components/bno08x/bno08x.c`,
   `components/bno08x/include/bno08x.h` sit modified on top of `cafc9f5`. **They
   are the only copy of the working I²C IMU driver.**

---

# 6. Motors + switch (added 2026-08-17, ALL VERIFIED)

## 3× ERM coin motors — 2N3904 low-side, 1 kΩ base, NO flyback diode (user's call)
Per motor: GPIO →1kΩ→ base (middle) | emitter (left) → GND | collector (right)
→ motor → 3.3 V. 2N3904 flat face toward you, legs down = E-B-C.

| GPIO | physical position (ID-verified by pulse test, mounted) |
|---|---|
| **17** | LEFT temple |
| **18** | CENTER forehead |
| **8**  | RIGHT temple |

Firmware: HAPTIC_GPIO_CENTER=18, RIGHT=8, LEFT=17 (main.c, flashed via OTA).

## Pause switch (SPDT)
COM (middle) → **GPIO 3** · one outer → GND · other outer unconnected.
Internal pullup; toward-GND = motors paused. Overrides `/api/haptics` web
toggle every frame. GPIO 3 is a strapping pin but safe (JTAG role needs an
unburned eFuse).

## Remote control endpoints (no reflash needed)
- `GET /api/motor?i=0..2&duty=0..255&ms=20..2000` — manual pulse (i:
  0=CENTER/18, 1=RIGHT/8, 2=LEFT/17 after the 2026-08-17 mapping fix)
- `GET /api/haptics?en=0|1` — software mute
- OTA: `curl --data-binary @build/vl53l8cx_esp32.bin http://<ip>/update`
  (saved the session twice when USB dropped)

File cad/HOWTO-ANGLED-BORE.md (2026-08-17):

# Cutting the camera bore at 22.5°, without typing 22.5

Same principle as the FOV cones: **borrow the angle from the geometry instead of
entering it.** Every angle you type is a number you can get wrong; every angle you
inherit from a face is correct by construction.

---

## The problem

The camera sits at 22.5° down. Its lens barrel is a Ø17.1 mm cylinder pointing along
that tilted axis. You need a hole through your housing wall that is **coaxial with
the barrel** — not perpendicular to the wall.

Cut it perpendicular to the wall and the barrel binds. Cut it at a typed 22.5° and
you're relying on the wall being at exactly the angle you assumed.

---

## Method — 5 steps

**Prerequisite:** the camera model must be in the assembly, positioned. If it isn't,
insert `cad/step/camera_hbv1716wa.step` and mate it first. The bore is derived from
the barrel, so the barrel has to exist.

### 1. Make a plane square to the lens
**Reference Geometry → Plane** → click the camera's **PCB front face** (or the lens
tip face — either works, both are square to the optical axis).

Set offset to anything convenient, or zero. **The plane arrives at 22.5° for free**,
because the camera is already at 22.5°.

### 2. Sketch on that plane

### 3. Steal the barrel's exact circle
Click the **barrel's circular edge** → **Convert Entities**.

This projects the real Ø17.1 mm circle into your sketch, **on the real axis**. Not a
circle you drew at coordinates you measured — *the* circle, linked to the part. If
the camera ever moves, this follows.

### 4. Add clearance
With the circle selected → **Offset Entities** → **0.35 mm**, direction **outward**.

That gives Ø17.8. Reasoning: 0.35 mm radial is the FDM figure from
`VERIFY-IT-YOURSELF.md` §6, and FDM holes print *undersized* anyway, so erring
generous is right for a bore.

Delete the original converted circle, or make it construction geometry — you want to
extrude the offset one.

### 5. Cut it
**Features → Extruded Cut → Through All**

Direction is automatically normal to your sketch plane, which is the lens axis.
Done.

The opening in the wall comes out as an **ellipse**, because a round hole through an
angled wall is an ellipse. That's correct — don't try to "fix" it.

---

## Check it

1. **Evaluate → Measure**, click the **bore's cylindrical face**, then the
   **barrel's cylindrical face**. Angle should read **0.00°** — coaxial.
2. **Section View** through the lens axis: you should see clear air all the way
   around the barrel, no pinch on either side of the wall.
3. Bore diameter **17.80 mm**.

---

## Related: keep the lens tip proud

Recessing the lens is the expensive mistake. At 119.58° horizontal, the half-angle is
59.79° and tan = 1.7175, so **every 1 mm of recess costs 3.4 mm of opening width**.

| Lens tip recessed by | Opening width needed | Opening height needed |
|---|---|---|
| 0 mm | 17.1 mm (just the bore) | 17.1 mm |
| 1 mm | 20.5 mm | 18.3 mm |
| 2 mm | 24.0 mm | 19.6 mm |
| 3 mm | 27.4 mm | 20.8 mm |
| 5 mm | 34.3 mm | 23.2 mm |

If the tip sits **at or proud of** the outer surface, none of this applies — the wall
physically cannot clip a field that starts in front of it. Just the Ø17.8 bore.

**Design rule: the lens tip is the forward-most point of the whole pod.**

---

## Where to put the camera — the two constraints

Full working: `python docs/camera_placement_check.py`

### A. Camera body must stay out of the ToF cones

Each ToF opens 22.5° upward. At Z mm forward of its aperture, the cone top is at
`0.41421 × Z`. The camera's worst point is its bottom edge, 19 mm below the lens axis
(38 mm square board).

> **lens axis height > 19 + 0.4142 × forward protrusion**

| Camera forward of ToF | Minimum lens-axis height |
|---|---|
| 0 mm | 19.0 mm |
| 10 mm | 23.1 mm |
| 20 mm | 27.3 mm |
| 30 mm | 31.4 mm |
| 50 mm | 39.7 mm |

### B. ToF boards must stay out of the camera's view — the harder one

The camera is 119.58° wide. Anything Z mm **forward of the lens tip** must be more
than `1.7175 × Z` sideways or it's in shot.

| Forward of lens tip | Must be sideways by |
|---|---|
| 5 mm | 8.6 mm |
| 10 mm | 17.2 mm |
| 20 mm | 34.3 mm |

A 51.5 mm ToF board sitting 10 mm in front of the lens would need to be 17.2 mm
clear sideways. It won't be — you'd get board in the corner of every frame.

**Which is why the answer to "is it fine for the lens to be in front of the ToF?" is
yes, and it's the right choice.** Nothing behind the lens tip plane can ever enter
the view, because the field only opens forward. That one rule satisfies constraint B
with no arithmetic at all.

Both constraints are met together by stacking the camera **above** the ToF pair with
the **lens tip proud of everything**:

| Position | ToF cones |
|---|---|
| 25 mm up, 0 mm forward | clear (needs ≥ 19.0) |
| 30 mm up, 20 mm forward | clear (needs ≥ 27.3) |
| 35 mm up, 35 mm forward | clear (needs ≥ 33.5) |
| 40 mm up, 50 mm forward | clear (needs ≥ 39.7) |

### Does the forward offset hurt the fusion?

**No.** It's just the Z component of the same translation vector Stage 3 already
solves for — a fixed constant, measured once, removed exactly. Same as the height.

It causes *occlusion*, not error: the camera peeks a few mm further around a near
object than the ToF does. Irrelevant for "is something in the way".

**What matters is rigidity.** Whatever offset you build, it must not change after you
calibrate.

---

## Measuring where the lens actually falls

The lens tip is **24.21 mm** in front of the camera PCB's front face
(25.90 total depth − 1.69 board). Barrel Ø**17.1 mm**. All [CALIPER].

1. **Evaluate → Measure**
2. Click the **lens tip face** (the flat annulus at the front of the barrel)
3. Ctrl-click a **ToF chip's top face**
4. Open the **Delta X/Y/Z** readout

Delta along the sight line = forward protrusion. Delta perpendicular = height offset.
Put those two numbers into the tables above.

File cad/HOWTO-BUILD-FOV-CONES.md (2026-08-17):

# Building the field-of-view cones yourself, in SOLIDWORKS

The whole trick: **don't type any angles.** Sketch on the sensor's own face, and
SOLIDWORKS derives the direction from the geometry. Type an angle and you're
trusting your arithmetic; borrow the face and you're trusting the model.

This also makes the cone **move with the sensor** automatically. No mates.

---

## The idea first, in plain terms

A time-of-flight sensor sees a square pyramid of space spreading out from its
window. The VL53L8CX's is **45° wide and 45° tall** (ST DS14161, Table 2).

"45° wide" means 22.5° either side of straight ahead. So if you start with a tiny
square at the sensor window and push it forward while flaring every side outward at
**22.5°**, you have drawn exactly what the sensor can see.

SOLIDWORKS has that exact operation built in: **Extrude with Draft.** Draft angle is
measured from the push direction — so a 22.5° outward draft *is* the 45° field.

That is the whole build. One sketch, one extrude.

> **Why 22.5 and not 45?** The 45° spec is the *total* angle, edge to edge. Draft is
> measured from the centreline. Half of 45 is 22.5. Getting this backwards gives you
> a 90° cone and everything downstream looks wrong.

---

## Build it — 8 steps

Work in **`fov_review\doubleTOFassem_FOVREVIEW.SLDASM`**, not your main file.

### 1. Start a new part inside the assembly
**Insert → Component → New Part**

Your cursor becomes a crosshair — SOLIDWORKS is asking where to put its first sketch.

### 2. Click the ToF chip's top face
Zoom right in on one SATEL board. The **VL53L8CX** is the small black package near
one end — **6.4 × 3.03 mm**, the only thing that shape on the board. Click its
**top face** (the flat one facing out, away from the PCB).

You are now editing a new part, in-context, with a sketch open on that face.

**This single click is what does all the work.** That face is the aperture plane, so
its normal is the optical axis. Both the 22.5° down-pitch and the 22° out-yaw are
now inherited from the board itself. Nothing to type, nothing to get wrong.

### 3. Sketch a small square on it
Draw a **1 mm × 1 mm** square roughly over the chip.

Now centre it properly:
- Ctrl-click the square's **centre point** and the chip face's silhouette
- or dimension it symmetric about the face's midpoint

1 mm is about the size of the real optical window, so this isn't a fudge — it's the
aperture.

### 4. Exit the sketch
Click the **exit-sketch corner** (top-right of the graphics area) or press **Ctrl+Q**.

### 5. Extrude it with draft
**Features → Extruded Boss/Base**

| Setting | Value |
|---|---|
| Direction | **away from the board** (use the flip arrow if it goes into the PCB) |
| End condition | **Blind** |
| Depth | **150 mm** |
| **Draft** | **ON** — click the draft icon |
| **Draft angle** | **22.5°** |
| **Draft outward** | ✅ **ticked** |

⚠️ **"Draft outward" is the one people miss.** Unticked, the pyramid tapers *inward*
and you get a spike instead of a view cone. If it looks like a needle, that's this.

Click ✓.

### 6. Leave the part
Click the **confirmation corner → Edit Component** to return to the assembly.

### 7. Make it transparent
Right-click the new part in the tree → the **beach-ball (Appearances)** icon →
**Transparency** slider to about **75%**.

### 8. Make it reference-only, so it can never be printed
Right-click the part → **Component Properties** → tick **Envelope**.

An Envelope component is SOLIDWORKS' own reference-geometry flag: excluded from the
bill of materials, excluded from mass properties, ignored by exports. That's the
"ghost part, material = air" idea you described — it's a real built-in feature.

Rename it in the tree to **`REF_fov_tof_A`** so it's obvious what it is.

### Repeat for the second sensor.

---

## Check your work — 3 measurements

Don't trust it because it looks right. Cones look right from almost any angle.

**a) Is the spread actually 45°?**
**Evaluate → Measure** → click **two opposite slanted faces** of the pyramid.
Angle should read **45.00°**.

**b) Is it pointing where the sensor points?**
**Measure** → the pyramid's **flat end face** (the big one, 150 mm out), then the
**chip's top face**. Angle should read **0.00°** — they're parallel, which is only
true if the cone is square to the sensor.

**c) Is it the right size at the far end?**
Click one edge of the big flat end face and read **Length**. For a 1 mm starting
square extruded 150 mm, it should be **125.26 mm** (SOLIDWORKS shows `12.53cm` if
your units are CGS).

> Where that comes from:
> `far edge = starting square + 2 × reach × tan(22.5°)`
> `= 1.0 + 2 × 150 × 0.41421 = 1.0 + 124.26 =` **125.26 mm**
>
> ⚠️ **Don't forget the starting square.** The spread alone is 124.26 mm, but the
> extrude begins from a 1 mm square rather than a point, so the finished edge is
> 1 mm longer. Sketch a different starting square and this number moves with it.
>
> If you measure ~300 mm, your draft was 45° instead of 22.5°. If you measure ~62 mm,
> the draft got applied to one side only.

**d) Does it move with the sensor?**
Drag the ToF board slightly. The cone should follow, then **Ctrl+Z**. If it doesn't
follow, the in-context reference didn't take — delete and redo from step 1, making
sure you clicked the chip face and not a plane.

---

## How long should the cone be? (why 150 mm and not 4000)

**150 mm is a drawing choice, not a spec.** The sensor really does range to 400 cm.
I picked 150 mm so the cone and the hardware fit on screen together.

| Reach | Spread alone | **Far edge, from a 1 mm square** | What it looks like |
|---|---|---|---|
| 100 mm | 82.84 mm | **83.84 mm** | about the size of the pod |
| **150 mm** | 124.26 mm | **125.26 mm** | pod still clearly visible |
| 300 mm | 248.53 mm | **249.53 mm** | pod getting small |
| 1000 mm | 828.43 mm | **829.43 mm** | pod is a speck |
| **4000 mm** | 3313.71 mm | **3314.71 mm** | a 3.3 m square — pod is 1/44th of the view |

Formula: `far edge = starting square + 0.82843 × reach`

The **far edge** column is what SOLIDWORKS reports when you measure the end face.

### The part that actually matters

**For checking whether the housing blocks the sensor, the length is irrelevant.**

The cone has perfectly straight sides. If the plastic clips the field, it clips it
**within the first few millimetres**, right at the aperture. Extending the cone from
150 mm to 4000 mm cannot reveal a new collision — there is no plastic out at 3 m.

So for the question the cone exists to answer, 150 mm is not a shortcut. It is the
complete answer, and 4000 mm is the same answer drawn 27× larger.

### When 4000 mm IS the right length

Different question — *coverage*: where do the two fans cross, does the pair clear a
doorway, how much floor is covered at walking distance. Then you want real range.

**Best of both:** build it at 150 mm, then just edit the extrude depth to 4000 when
you want the room view and back again. It's one number in one feature — double-click
the extrude in the tree, retype the depth, rebuild. Nothing else changes.

### About that 400 cm — it's real, but conditional

Verified from ST's own documents, not the marketing line:

- **UM3109 p1:** "8x8 zones (64 zones) and can work at fast speeds (60 Hz) up to
  400 cm"
- **SATEL-VL53L8 datasheet p1:** "accurate ranging up to 400 cm with a 65° diagonal
  FoV"

⚠️ But **UM3109 Table 2** (p9) gives the frequency limits, and they are not the same
for both resolutions:

| Resolution | Min freq | **Max freq** |
|---|---|---|
| 4×4 (16 zones) | 1 Hz | **60 Hz** |
| **8×8 (64 zones)** | 1 Hz | **15 Hz** |

So the "60 Hz" in that headline sentence belongs to **4×4**. In the 8×8 mode you're
using, the ceiling is **15 Hz**.

Also **UM3109 §4.5**: max ranging distance and ambient immunity are better in
**Continuous** mode, but the default is **Autonomous** (VCSEL only fires part of the
time, to save power). 400 cm is a best case — continuous mode, a good reflective
target, low ambient IR. Outdoors in sunlight against dark clothing you will get far
less. Treat 400 cm as the ceiling, not the working figure.

---

## The camera cone — different, and here's why

The camera is **119.58° × 63.12°** (measured, `camera/calibration_720p.txt`, RMS
0.30 px). Those two numbers are different, so **draft will not work** — draft applies
the same angle all the way round.

Use a **Loft** between two rectangles instead:

1. Sketch on the **lens tip face**: a small rectangle, roughly 2 × 1 mm.
2. **Reference Geometry → Plane**, offset **150 mm** from that face, out in front.
3. Sketch on the new plane: a rectangle **514.76 mm wide × 184.12 mm tall**,
   centred on the same axis.
4. **Features → Lofted Boss/Base**, pick the two rectangles.

> Where those come from:
> width = 2 × 150 × tan(119.58/2) = 2 × 150 × 1.71586 = **514.76 mm**
> height = 2 × 150 × tan(63.12/2) = 2 × 150 × 0.61374 = **184.12 mm**

⚠️ Make sure the wide dimension lines up with the camera's **wide** axis. A sensor
rotated 90° is the classic way to get a cone that's confidently, precisely wrong.

**Check:** Measure between two opposite side faces → **119.58°**. Top and bottom →
**63.12°**.

---

## One thing the cone will not tell you

A field-of-view cone shows where the sensor *could* see. It doesn't show what it can
*actually* see once the housing is around it — for that, the cone has to be
intersected with the plastic.

That's what `cad/check_user_assembly.py` does. Re-export a STEP and run it whenever
you change the enclosure. Right now it reports both sensors clear, but only because
there's no front wall in front of them yet.

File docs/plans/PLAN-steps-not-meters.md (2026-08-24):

# PLAN — Steps, not meters (user-calibrated stride distances)

Status: plan only, 2026-08-23. Implements the UTILITY-ROADMAP delivery
invariant: "CHANGE: distances in **steps** (user-calibrated stride), not
meters" (docs/UTILITY-ROADMAP.md §Delivery invariants), and the Phase U3
phrasing target "end of the line, left, about six steps".

## Goal

Speak walking-relevant distances as calibrated steps ("about six steps")
instead of meters. Steps are body-scaled: a blind pedestrian executes "six
steps" directly; "three meters" requires a mental conversion mid-walk. Keep
meters available in the stationary query context (F9) via a setting, because
F9 is an aiming/survey tool, not a locomotion cue.

## Evidence — where every spoken distance in cv_fusion.py originates

Audit of `camera/cv_fusion.py` (all spoken text goes through `speech_next` /
`_say_q`):

1. **`spoken_range(mm)` (line 565)** — the old "bare number = meters,
   half-meter steps, 'close' under 0.75 m" formatter. **DEAD CODE since
   tier-engine v2**: grep shows zero call sites (the v2 engine removed
   numbers from caution callouts — "No numbers -- the ticker carries
   proximity", line 1096-1097). It is the natural home for the new
   step formatter.
2. **F9 on-demand scene query (lines 1122-1149)** — the only autonomous-loop
   place that speaks numbers today: `"{nm} {direction_word(az)}, about
   {'1 meter' if m < 1.3 else f'{m:.0f} meters'}"` (lines 1138-1139) and the
   obstacle fallback `"obstacle {direction_word(az)}, about
   {max(1, round(zn['z']/1000))} meters"` (lines 1144-1145).
3. **Door scan announcement, `_door_scan()` (line 853)** —
   `f"door {i+1}, {hr} o'clock, about {m:.0f} meters"`. This is a WALKING
   context: the user is about to travel to the door.
4. **Not spoken, don't touch**: the VLM sensor context string
   `f"{d['name']} {d['range_mm']/1000:.1f}m"` (line 1419) is prompt text for
   the cloud model; on-screen overlays (lines 989, 1000) are sighted-observer
   UI. Directive/caution tiers speak no numbers at all (by design), so the
   ticker and tier engine are untouched by this plan.

## Design

**Stride constant.** `STRIDE_M`, persisted in `camera/stride_cal.json`
(git-ignored, like `vlm_log.jsonl` — add to `.gitignore`):
`{"stride_m": 0.68, "steps_counted": 15, "dist_m": 10.0, "t": "..."}`.
Default when the file is absent: 0.7 m (typical adult walking stride;
mark output hedged with "about" always). Loaded once at `main()` startup
next to the mount-cal load (line 690).

**30-second calibration** (no new hardware; two interchangeable protocols):

- *Known distance*: user stands at one end of a pre-measured path (e.g. a
  10 m hallway, tape-measured once). Press `k` (new key) → "calibration:
  walk your marked distance, press k when you arrive, counting steps" →
  walk → press `k` → the device asks nothing; user then presses digit keys
  or speaks the count? Too fiddly. Simpler: **count-steps-over-measured-path
  via CLI**: `python camera/cv_fusion.py --calibrate-stride` prompts in the
  console: "distance walked (m)?" and "steps taken?", writes
  `stride_cal.json`, exits. Done once per user, sub-30-seconds, zero
  in-loop UI.
- *Optional later upgrade*: the BNO085 step counter (imu-uses-2026-08-17.md
  Tier C item 13, ~1% count error head-worn) can count the steps
  automatically over the measured path — one `sh2_setSensorConfig` call —
  removing the manual count. Not in scope for v1.

**Conversion + phrasing rule** (replaces the body of `spoken_range`):

```
def spoken_steps(mm):            # rename/repurpose spoken_range (line 565)
    steps = (mm / 1000.0) / STRIDE_M
    if steps < 2:   return "right there"
    if steps <= 20: return f"about {int(round(steps))} steps"
    return f"about {mm/1000.0:.0f} meters"     # steps stop being countable
```

Whole steps only, always "about" (association coarseness + stride variance
make single-step precision dishonest). Above ~20 steps the count loses
meaning — fall back to meters (matches Tier C item 13's honesty note:
"'about 30 metres' honest, '31.4 m' not").

**Setting / toggle.** New CLI flag `--units {steps,meters,auto}`, default
`auto`:
- `auto`: door-scan announcements (walking context) → steps; F9 (stationary
  survey) → meters.
- `steps` / `meters`: force everywhere.
Runtime toggle: new key `u` cycles the mode and speaks it ("units: steps"),
wired into the key dispatch block (lines 1400-1503).

## Implementation steps

1. `camera/cv_fusion.py` line 565: repurpose dead `spoken_range()` into
   `spoken_steps(mm)` per the design above; module-global `STRIDE_M` with
   0.7 default.
2. `main()` near line 690 (mount-cal load): load
   `camera/stride_cal.json` if present, set `STRIDE_M`, print confirmation.
3. Add `--calibrate-stride` early-exit branch in `main()` (before camera
   open): console prompts, compute `dist/steps`, sanity-check 0.4-1.0 m
   (reject and re-ask outside that), write JSON, print result, exit.
4. Add `--units` argparse flag (near line 636) + `units` state variable +
   `u` key handler in the dispatch block (lines 1400-1503).
5. F9 block (lines 1138-1145): route both number phrases through a helper
   `spoken_dist(mm, context="query")` that picks steps/meters from the
   units mode + context.
6. `_door_scan()` line 853: same helper with `context="walking"` →
   "door 1, ten o'clock, about six steps".
7. `.gitignore`: add `camera/stride_cal.json`.
8. `docs/DEVLOG.md`: entry per the portfolio-documentation rule.

## Test plan

- Unit-style REPL check: `spoken_steps()` at 500/1400/4900/20000 mm with
  stride 0.7 → "right there" / "about 2 steps" / "about 7 steps" /
  "about 20 meters".
- Calibration flow: run `--calibrate-stride`, enter 10 m / 14 steps, confirm
  file contents and reload on next launch.
- Live: stand a measured 4 m from a door, run door scan → spoken step count
  should match a real walk to the door within ±1 step.
- F9 in `auto` still says meters; after pressing `u` twice (force steps),
  F9 says steps. F8/audio and tier engine unaffected (no numbers there).

## Risks

- Stride length varies with speed and clutter (short cautious steps indoors);
  a single constant is ±20% in practice. Mitigation: "about" hedging, whole
  steps, meters fallback past 20 steps. Note for the writeup, don't
  over-engineer.
- Users trained on the old meter phrases (just Reuben for now) — trivial.
- `spoken_range` deletion: confirmed no call sites, but re-grep before
  removing.

## Effort

~3-4 h total: 1 h formatter+setting, 1 h calibration CLI, 1 h wiring both
call sites + toggle, 0.5-1 h live test + DEVLOG.

## Dependencies

None on other plans. Synergy: the session logger (PLAN-fp-hour-intervention-
logging) should record the units mode per session so alert phrasing is
reproducible. Optional future: IMU step counter (firmware one-liner) for
automatic calibration and "about 30 steps since the doorway" odometry.

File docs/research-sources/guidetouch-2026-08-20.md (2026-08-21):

# GuideTouch (arXiv:2601.13813, Skoltech, Jan 2026) — review — 2026-08-20

You flagged this PDF. Directly relevant: **2× VL53L5CX (our sensor's
predecessor) + ESP32 + 4 vibrotactile motors**, scarf-worn on
shoulders/chest, ~$100 BOM, 500 g, 12 h battery. No camera by design
(they call YOLO-class compute "bulky" — our laptop/Jetson path
sidesteps their constraint).

## What validates our decisions

1. **Their n=28 blind needs-interview ranks the same three gaps we
   prioritized**: (a) head-level hazards — "most frequent and
   dangerous," (b) drop-offs/ground risks (manholes, stairs), (c) thin
   objects (poles, bollards). Matches our head-clearance ✅, drop-off
   carve-out, and the CLOSEST-target-order fix for thin objects.
2. "More than 40% of blind individuals report head-level injuries or
   falls every few months" (their framing of the UCSC survey — same
   source lineage as our 13%/month stat).
3. Their interviews: replacing the cane is "highly undesirable" —
   third independent confirmation of your cane-alongside ruling.
4. **Haptic vocabulary must stay small — now with numbers**: pattern
   recognition 92.9% for 1–2 motor patterns but **78.4% when 3–4 motor
   combos are included**; errors concentrate in complex patterns
   (ANOVA p<1e-6). Blind users: 93.75% on primary directional cues.
   → Rule for our 3 temple motors: **never fire 3-motor patterns as
   vocabulary; ≤2 simultaneous, and prefer 1.**

## Stealable ideas (→ IDEA-BANK)

- **Drop alarm**: collar clip + buzzer — if the device falls off, it
  beeps (3–4 kHz) so a blind user can find it. Trivially cheap, real
  problem (a dropped helmet is invisible to its owner).
- **Vertical ToF splay**: their two sensors pitch 30° apart → 90°
  combined VERTICAL field (knee 30 cm to head 160 cm at just 50 cm
  standoff). Ours are yawed ±22.5° horizontally. A future third sensor
  (or re-aim experiment) could buy the same vertical coverage for the
  head-clearance + drop-off missions.
- **Rain: spinning optical cover** (3000 rpm BLDC centrifugal
  self-cleaning; beat ultrasonic + vibration in their tests, 18/20
  droplets cleared) — clever but **70 dB at head level**; our $5
  hydrophobic-coating + brim idea remains the sane version. Noted as
  the only tested-working active option.
- Detection floor math: obstacle needs ~30% of a zone; 4 cm object
  detectable at 1 m (useful cross-check for our thin-object math).

## Their weaknesses (our openings)

Static-condition lab evaluation only (no walking trials); no camera →
no labels, no guidance, no text; 4×4-era sensor; no head protection
geometry (chest-worn misses the "duck!" case); no spatial audio.

## References worth chasing later

- Xu 2023 "Intelligent Head-Mounted Obstacle Avoidance Wearable"
  (Sensors 23:9598) — head-mounted prior art, check against our
  novelty claims.
- LLM-Glasses (arXiv:2503.16475) + HapticVLM — same lab's VLM+haptics
  line.
- Gao 2025 Nature Comms cross-modal wearable (10.1038/s41467-025-58085-x).

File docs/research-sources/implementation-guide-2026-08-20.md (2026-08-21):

# IMPLEMENTATION DEEP-DIVE — doorway, head-height, transit, cars, crosswalk — 2026-08-20

The synthesis you ordered: "more research on doing it as well as possible"
for doorways/entrances, head-height obstacles, bus/transport (incl. getting
into cars), crosswalk alignment. Five research streams, condensed-verbatim.
Component docs with full citations sit beside this one in research-sources/.

---

## Cross-cutting findings (these change HARDWARE, not code)

**1. The fisheye is the binding constraint — three independent streams
converged on it.**
- Plate OCR: 1080p @ 119.58° → 20 px character height only to **3.2 m**.
  A 38° lens on the same sensor reaches **10.1 m**.
- Bus route number (0.15 m LED char, ≥24 px floor): **2.8 px at 30 m,
  8.4 px at 10 m**. Tangsuksant 2019 independently measured a **15 m
  ceiling** for a 15 cm numeral.
- Manduchi & Coughlan "The Last Meter" CHI 2014 (18 blind participants,
  guided to within 30 cm): "increasing the field of view does not help,
  and may even hurt, performance."

→ **Add a second boresighted ~38–50° global-shutter camera with manual
exposure.** Fisheye = scene/obstacle/acquisition; tele = text + last
metre. Global shutter also kills LED-sign banding at source.

**2. The BNO085 is load-bearing, and mag-free is right.**
- Head pitch during gait is **8° ± 2°** = ±140 mm vertical error at 2 m —
  larger than the whole head-clearance margin. Error budget: uncompensated
  ≈ 190 mm RSS; gravity-compensated ≈ 130 mm.
- Crosswalk: latch heading at the curb, dead-reckon across. 10 s crossing
  at pessimistic 2°/min drift = **~7 cm lateral** vs ~3.6 m biological
  veer. Only the delta matters — exactly why mag-free works.

**3. False-alarm economy is the dominant risk — hard evidence.** Pittet
et al., Sci. Rep. 2026 (13 BVI users, 28 m course): cane alone 2.92 body
collisions; cane + depth-camera device 1.62; cane + BuzzClip ultrasonic
**3.54 — worse than no device**, while slowing users 16%. Silence must be
the default everywhere.

---

## 1. Doorway / entrance terminal guidance

- **Calibrate to Antonazzi 2025 (J. Field Robotics)**: generic door
  detector in an UNSEEN environment = **13–48 mAP**. Fine-tuned on just
  15% of target-environment annotations: 20 → 76 mAP; at 75%, 96 mAP.
  **Domain adaptation, not architecture, is the whole game.** Their
  metrics to steal: TP% / FP% / BFD% (background false detection — the
  one that matters; announcing a door that isn't there walks the user
  into a wall confidently).
- Datasets are weak (DoorDetect 1,213 imgs; DeepDoors2 6,000). Neither
  has fisheye, storefronts, glass, hinge labels. **Plan our own capture
  loop**: Grounding DINO / OWLv2 as offline auto-labellers, hand-correct,
  nightly YOLO fine-tune. The loop beats any model choice.
- YOLO-World (35.4 AP LVIS @ 52 FPS) = prompt-driven classes without
  retraining. Fisheye caveat: polygon representations beat axis-aligned
  boxes by 40.3% mIoU on fisheye (Rashed 2020) — a peripheral box is
  mostly wall, which wrecks ToF association.
- **Door STATE from geometry, not a classifier**: closed door is coplanar
  with the wall; open = depth discontinuity past it. Our two 8×8 grids
  give two horizontal slices — fit the plane, get open/closed from the
  offset sign. "Traversable now" is the semantically correct target.
- **Hinge side**: detect door + handle, infer from spatial relationship
  (handle left → hinge right) — Watanabe & Premachandra 2026. OCR of
  PUSH/PULL overrides.
- **Glass is the hardest part.** Through glass a ToF beam returns the
  glass, the object behind, or a reflection — three wrong answers,
  non-deterministically per zone. Template = **TOPGN** (arXiv:2408.05608):
  use return INTENSITY, not range (+12.7% F-score, ~50 Hz on CPU). On the
  VL53L8CX: suspect when `target_status ∉ {5,9}` or `nb_target_detected
  ≥ 2` or `range_sigma_mm` spikes; specular when `signal_per_spad` high
  but implied reflectance implausible; then require **spatial coherence**
  (glass = rectangular patch, noise = scatter). IMU bonus: as the head
  rotates, a real plane holds in world frame, specular ghosts swing.
  **OPEN RISK: TOPGN was proven on dense LiDAR; whether 64 zones carry
  the coherence structure is unverified — prototype week one.**
- **Apple Detection Mode** (verified, iPhone User Guide): announces
  distance → open/closed → attributes (how to open) → door decorations
  (reads signs near the door). Four toggleable channels; double-tap for
  more detail. Lessons: continuous cheap channel + ON-DEMAND rich channel;
  read the signage.
- **Terminal-phase UX**: Ahmetovic "Turn Right" ASSETS 2018 — blind users
  **overshoot rotations by 17° average, worst on slight turns**. Never
  issue discrete small-angle commands close-in; use continuous closed-loop
  null-seeking on the three temple motors. Vibrotactile beats voice by
  >25% task time for localization.
- Elevator panels: public dataset of 3,718 panel images / 35,100 buttons
  + MIT code (zhudelong/elevator_button_recognition).
- **Storefront vs display window: no published work — ours to invent.**
  Strongest cue is ground-plane continuity across the threshold (walkable
  floor = entrance; sill at 0.4–1.0 m = window). Add metric width
  (pedestrian 0.8–1.1 m, double 1.6–2.0, garage 2.4–5), handle height,
  OCR. Ruleset, not learned — we have no labels.

## 2. Head-height obstacles

- **The justifying stat** (Manduchi & Coughlan CACM 2012, survey n=300):
  **"13% experience head-level accidents at least once a month"** — and
  frequency did NOT differ between cane and dog users. Neither aid covers
  it.
- **Code-backed framing**: ADA §307 — cane-detectable below 27 in,
  clearance required above 80 in (2032 mm). **The 27–80 in band is "cane
  misses it, code says it shouldn't be there."**
- **Critique of our top-ray rule — one fatal flaw**: there is no fixed
  "top row." Head clearance only exists in a GRAVITY-ALIGNED frame; a
  fixed sensor-frame ray points at wildly different heights with posture.
  Closest prior art (Muñoz 2025, forehead ZED + Jetson) DISCARDED frames
  when the user looked up/down; we can compensate with the IMU instead —
  and that gap is our novelty claim.
- **Hard ceiling**: under an ADA-minimum 2032 mm doorway a 1.90 m user
  has only **130 mm** of legal clearance — uncompensated error (190 mm)
  exceeds it. **The 10–15 cm rule is viable ONLY with IMU gravity
  compensation.** Widen to 30 cm uncompensated and tall users get alerted
  in every legal doorway → net-harmful per Pittet.
- Alert distances (τ ≈ 0.8–1.0 s dead time): first alert ≥ 2.0 m, hard
  alert 1.2 m, below 0.8 m already failed. Blind cane speed 0.68 m/s →
  comfortable.
- **Sensor settings that decide success**:
  - **Target order → CLOSEST, not default STRONGEST.** A 3 cm branch at
    2 m fills ~2% of a zone — under STRONGEST the background wins and
    **the branch is silently invisible. Single highest-leverage change in
    the system.**
  - Enable multi-target (600 mm merge limit = branch merges with wall
    behind — document).
  - Raise sharpener above 5% default (mixed-pixel edges).
- **Awning vs branch — no published solution**: (a) planarity/extent,
  (b) closing rate must match own IMU forward speed, (c) 3-of-5
  persistence (200–330 ms) — cheapest and most effective.
- **Architectural inversion**: camera = primary EXISTENCE detector, ToF =
  metric range confirmer. ToF fails SILENTLY on the highest-value targets
  (wet bark, matte black, glass, oblique + sunlight). A detector whose
  worst failure is silence must not decide to stay quiet. Camera-says /
  ToF-silent → trust the camera, range from ground plane.

## 3. Public transport

- **Highest-leverage, lowest-cost item in the whole report: fuse
  GTFS-Realtime day one.** GPS + stops.txt → the complete legal set of
  route strings at this pole (a handful). TripUpdates + STOPPED_AT often
  leave ONE candidate. **Open-set LED OCR becomes closed-set
  classification over K strings** — edit-distance scoring kills "R4"→"84".
  `trip_headsign` gives the destination WITHOUT reading it. TransLink
  endpoints free & documented (see transit-gtfs-navilens doc). 90 s
  staleness ⇒ RT proposes, vision confirms, never the reverse.
- **Bus stop finding is SOLVED — cite All_Aboard (Luo lab, TVST 2024),
  don't rebuild**: 91% vs Google Maps 52%; final gap 1.8 m vs 7.0 m; its
  4-level homing tone is one of two validated audio encodings in the
  boarding literature.
- **Route-number OCR best number**: SRM-OCR on BusLED-700 (2025) —
  **85.1%** on real degraded LED signs. Pipeline: DBNet++ 5–10 Hz →
  ByteTrack → PARSeq (14.9 ms) on tracked crops → per-character
  confidence-weighted voting over 5–10 frames (+4.6 to +10.5 pts; also
  washes out banding). TrOCR disqualified (huge, slow, worse on curved).
  **Constrain the charset per field** — language models hallucinate on
  contextless 3-digit route numbers; consider per-digit object detection
  (100% on 438 seven-segment digits). Read on approach only — transverse
  pass at 5 m smears 9 px per 10 ms.
- **"Which door is the bus door": ZERO arXiv hits for the phrase — a
  genuine novelty claim.** IBM/Asakawa have no bus work (full DBLP
  sweep). Transferable: LineChaser CHI 2021 "advance now" cue.
- **Platform edge**: Japan FY2021 = 1,429 platform falls; survey: **76%
  of blind respondents had fallen off a platform, 91% near-falls**; 64%
  of stations have no screen doors, rollout ~62 stations/yr — the market
  stays for decades. Tactile-paving segmentation is mature (mIoU ~94.9%,
  59 fps embedded) but NO public dataset splits warning-dots from
  directional-bars — relabel. Geometry: helmet ToF usable ground strip
  1.2–3.6 m; stopping needs 1.95 m at 1.4 m/s → clears in ideal light
  only. Drop-off signature (coherent band of zones flipping to
  no-return) is identical to black mat/puddle/sun — **false-positive
  discrimination IS the problem** (EyeCane's downward sensor has a
  documented step-failure record). Japan's interior-line warning blocks
  are ASYMMETRIC — they tell which side is safe, which depth can't.
  Consider chest/waist ToF mount (buys 0.2–0.25 m slant).

## 3b. Rideshare / getting into cars

- **The gap is real**: Uber/Lyft ship only visual (Beacon/Amp) or
  verbal-at-contact affordances — nothing helps a blind rider LOCATE the
  car. US v. Uber (settled 2022, ~$2.2M over wait-time fees) documents
  the boarding interval as where blind riders lose.
- **Plate OCR the decisive numbers** (UFPR-SR-Plates 2025): single
  low-res frame **1.7%** → +super-resolution 31.1% → **+majority vote
  per character position over 5 frames = 44.7%**. Best multi-frame
  method 96.7%; competition winners ~82% — **1 in 5 wrong even at SOTA.
  Fail-closed is mandatory.**
- Night: plates are retroreflective — force MANUAL exposure on the tele
  camera, expose for the plate. Auto-exposure beside headlights kills the
  8 pm demo. **BC has rear-only plates** — an approaching car has no
  plate; the plate pipeline is post-stop CONFIRMATION, never approach
  announcement.
- **1:1 verification, not classification** — the app hands us
  plate/make/model/colour. LLR scorer: plate ≥5/7 chars, zero
  contradicted ≈ +15 (decisive alone); make/model +2; colour +1.5 day /
  **+0.3 night** (silver/white/grey collapse under street lighting); any
  contradicted plate char = hard reject. "Confirmed" ≥ 12 — unreachable
  without a plate.
- **Don't try to see the door handle** (no dataset; geometry against us;
  flush EV handles). O&M answer: localize the door seam / B-pillar /
  window line at 2–4 m, then hand off to touch: "hand on the car, slide
  down and right 20 cm."
- **Safety non-negotiables**: no plate read → never "this is your ride"
  (two black Camrys). Moving-vehicle interlock — never "step forward"
  unless ToF confirms zero closing velocity N frames — as a SEPARATE
  auditable module with its own tests.
- **Unglamorous go/no-go: getting plate/make/model out of the Uber app**
  (no public rider API — accessibility-tree scraping, screen OCR, or the
  user speaks it). Solve first.

## 4. Crosswalk alignment

- **The architecture-deciding finding** (Kallie 2007): veer is a RANDOM
  WALK in heading, not a fixed bias — initial-pointing cues did NOT
  reduce it. **Open-loop alignment is worthless past ~4 m; "learn the
  user's bias" is dead. Continuous closed-loop correction the whole way
  across.** No published system does mid-crossing correction in traffic
  (Crosswatch tells users to pocket the phone before crossing) — genuine
  contribution.
- Veer magnitude (Guth 2018, 22 m simulated crossing): unaided ≈ 3.6 m
  lateral ≈ 9.2° effective; beaconing cut it ~5×. (Units caveat: PMC
  prints "ft," geometrically must be inches — verify before quoting.)
  APS benchmark: "ended within crosswalk" 23.2% → 76.7% with a far-side
  cue. **Verbal descriptions do NOT help staying in the crosswalk** —
  never solve veer with speech.
- **Curb-ramp trap** (FHWA primary): diagonal ramps point ~45° off BOTH
  crossings — users align to ramp slope and walk into the intersection
  centre. (Scott JVIB 2011 is the paywalled key cite — interlibrary.)
- **Recommended algorithm — BEV-first (our real edge)**: fisheye →
  undistort → inverse-perspective-map to bird's-eye using IMU gravity +
  helmet height → light seg on the BEV tile → RANSAC stripe fit →
  geometric validators (alternating polarity, width monotonicity,
  cross-ratio ≈ 1/4 — Crosswatch 2008's principled FP rejection: 72% TPR
  at 0.5% FPR) → 1 s circular median → LATCH heading at commit →
  cross-track control (heading delta + lateral offset — heading-only
  never fixes "parallel but 1 m left") → deadband ±5° / ±0.5 m → 1.0–1.2
  Hz L/R temple haptic. Everyone else runs detection on the perspective
  image; live per-frame IPM off the IMU is the update Murali/Coughlan
  2013 was waiting for.
- Dataset: **CDSet-3434** (HuggingFace, Apache-2.0 — day/rain/night/
  damaged/glare) + CDNet's SSVM temporal module (F1 +13 @288, 33 fps on
  Jetson Nano). Mapillary Vistas for pedestrian-perspective pixels;
  Cityscapes has NO crosswalk class.
- **UX**: bone conduction only; mostly silent (Coughlan & Shen 2013:
  tones inaudible at busy corners, users preferred vibration). One
  utterance at curb → haptic align → double-pulse aligned → **silence =
  on-track** → drift pulses at 1.0–1.2 Hz (validated cadence) only
  outside deadband → ToF-triggered "curb, 2 metres." Direction by motor
  LOCATION never rhythm; avoid pitch-as-distance (only 59% map it
  intuitively). Fewer instructions = better clarity AND safety
  (Parsimonious Instructions, IMWUT 2025). Keep detector→haptic <150 ms.
- **The real project: bearing PRECISION.** Published systems report
  detection %, almost never bearing degrees; we need ±3° to beat 9° veer,
  and the literature is silent on whether pedestrian-height worn-paint
  gets there. **Build the ground-truth rig before the detector.** Wet
  night asphalt (the Vancouver case) has no published numbers — expect
  gyro-only fallback from the curb latch, which is why the dead-reckon
  stage must work standalone.
- **Asymmetry over everything: a confidently-wrong correction steers a
  blind person into traffic.** Gate hard on confidence; prefer "crosswalk
  not detected."

---

## DO THESE THREE FIRST

1. **Sunlight bench test, VL53L8CX** — ambient derating is the
   load-bearing unknown for platform-edge AND head-clearance margins.
2. **Glass coherence test on the 8×8 grid** — TOPGN unverified at 64
   zones; know early if we need different hardware.
3. **Order the second camera** (~38–50°, global shutter, manual
   exposure) — three independent analyses say the fisheye can't do text
   or the last metre. Optics; no model fixes it.

## Genuine novelty claims (portfolio)

1. Continuous mid-crossing veer correction in traffic (nobody does it)
2. Ground-plane-referenced overhead clearance with IMU compensation
   (Muñoz explicitly doesn't)
3. Bus door localization from the sidewalk (zero literature)
4. GTFS-RT × camera fusion (no shipping product)
5. Car-door-handle dataset from pedestrian height (doesn't exist, cheap
   to collect)

## Sourcing caveats

WebSearch quotas exhausted; all via direct fetches (arXiv, Crossref,
OpenAlex, Europe PMC, vendor pages). Re-verify: ST UM3109 target-order
semantics + daylight range (st.com timed out), BNO085 GRV drift spec,
Mapillary class list, Guth 2018 ft/inches. Paywalled keys worth chasing:
Scott JVIB 2011 (alignment cues), Manduchi & Kurniawan AER 2011
(head-level accident breakdown).

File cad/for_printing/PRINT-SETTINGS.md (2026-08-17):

# Print settings — helmet sensor pod

Drop the exported 3MF/STL files in this folder and send the whole folder.

---

## Parts and quantities

| Part | Qty | Notes |
|---|---|---|
| ToF sensor case | **2** | mirrored pair — same file, two copies |
| Centre wedge | 1 | |
| Camera mount baseplate | 1 | 22.5° wedge |
| Camera wall | 1 | |

*(update this list to match what's actually in the folder)*

---

## Material

**PLA.** Stiffer than PETG, which is what matters here — the whole assembly holds a
camera and two depth sensors in fixed alignment, and any flex or creep invalidates the
calibration. PETG only if it'll ever sit in a hot car.

---

## Settings

| Setting | Value |
|---|---|
| Nozzle | 0.4 mm |
| Layer height | **0.2 mm** (0.15 mm if hole accuracy matters more than time) |
| **Perimeters / walls** | **4** ← not the default 2 |
| Infill | **25–30%**, gyroid or grid |
| Top / bottom layers | 4–5 |
| Supports | only where an overhang exceeds ~45° |
| Brim | optional, helps on the small parts |

**Perimeters matter far more than infill on parts this size.** Going from 2 to 4 walls
costs minutes and adds a lot of strength; pushing infill to 80% costs hours and adds
little.

---

## ⚠️ Orientation — the single biggest factor

Layers bond weakly to each other, so a printed part is strong **across** layers and weak
**along** them. Orient each part so loads press across layers rather than peeling them
apart.

| Part | Orientation |
|---|---|
| **Camera mount baseplate** | **flat bottom on the bed** — no supports, and the screw loads press across layers |
| **ToF sensor cases** | largest flat face down |
| **Screw bosses** | hole axis **vertical** where possible — rounder, cleaner holes |

**Do not print the 22.5° faces at an angle to the bed** if it can be avoided.

---

## ⚠️ Holes print undersized

A modelled 1.6 mm hole typically comes out **1.4–1.5 mm** on FDM. That's helpful for
self-tapping screws (more material to bite) but it can make driving hard enough to split
a boss.

**Print one test coupon first** — a small block with one Ø1.6 pilot, one Ø5.2 clearance
hole and one M5 nut pocket. Five minutes, and it tells you how much this printer
undersizes before committing a four-hour part.

**Do not scale or "fix" hole sizes** without checking — the clearances were calculated
against specific hardware.

---

## Hardware these parts are designed around

| | |
|---|---|
| Case joint | **M2 × 12** hex socket cap (ISO 4762) |
| Camera mount | **M2** self-tapping into Ø1.6 pilots |
| Baseplate | **M5 × 20** with 1.4 mm washers and 3.8 mm nuts |
| Lid | **M3 heat-set inserts** |

**Do not scale the parts.** Every clearance is sized to these fasteners.

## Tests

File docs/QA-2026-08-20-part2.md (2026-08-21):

# Your questions answered, round 2 — 2026-08-20 evening (indoor-nav doc feedback)

## 1. Bluetooth bone-conduction latency — your fear is correct

Measured: standard Bluetooth (SBC codec, which **every Shokz model
uses**) = **257–260 ms, and it jitters**. For head-tracked spatial ticks
that's disqualifying: turn your head at 90°/s and the tick lands ~23°
away from the obstacle — actively wrong during the exact moment you're
scanning. Open-ear makes it worse: you hear the real world at 0 ms, so
the lag is glaring (detection threshold ≈ 30 ms).

**Split the audio into two channels:**
- **Spatial ticks/beacons → wired DIY**: 2 bone-conduction transducers
  bonded to the helmet shell (Dayton BCE-1 $76, or 2× $16.62 generic
  drivers + $5 amp). Zero latency, and the transducers sit at a KNOWN
  pose relative to the IMU — a consumer band shifts independently and
  breaks the spatial math.
- **Speech/menus → any Bluetooth open-ear is fine** (260 ms doesn't hurt
  sentences). Soundcore V30i $44.99 if you want one.
Full guide: [[feasibility-pack-2026-08-20]] §6.

## 2. What are IR projectors (.lumen's)?

Infrared floodlights/pattern projectors — they light the scene with
wavelengths humans can't see, so the cameras can see in darkness (same
idea as security-camera night vision). .lumen ships 2 IR *laser*
projectors, which also project a dot pattern that gives their cameras
texture to compute depth from on blank walls. Our version is already in
IDEA-BANK §C: cheap IR LED floods (~$10) would let our camera work at
night — and note our ToF is ALREADY active-IR, so unlike Glide we don't
go blind in the dark; only the camera does.

## 3. "Glide = stereo + mmWave" — what I meant

- **Stereo-depth cameras**: two cameras a known distance apart; depth
  computed from parallax, like your two eyes. Glide's FAQ confirms two
  stereo-depth cameras in the handle. Passive (needs light — hence
  Glide's darkness limitation).
- **mmWave radar**: millimetre-wavelength radio sensing — works through
  rain, fog, darkness; sees moving things extremely well. I flagged it
  in the indoor-nav doc as the rain-immune sensor CLASS in that product
  space (and as our deferred option — cheap modules have no azimuth
  resolution, i.e. they say "something at 2 m" but not where). Glide
  itself is camera-based per its FAQ; treat any mmWave attribution to
  Glide as unconfirmed.

## 4. How does biped NOA work?

Shoulder-worn harness (like a collar draped over both shoulders): **3
ultra-wide cameras** (~170° combined), an NVIDIA Jetson-class computer
on the harness, and **self-driving-derived software** — it tracks every
moving object, predicts each one's trajectory a few seconds out, and
warns ONLY about things on a collision course with you (their pitch:
"like a self-driving car for pedestrians"). Output = 3D spatial beeps
through headphones from the direction of the threat + GPS turn-by-turn.
That trajectory-prediction filter is their one great idea and it's
already in our IDEA-BANK (§D "trajectory-prediction alerts" — ByteTrack
velocity + own motion → per-object TTC). Caveat: biped.ai's domain has
been dead in all our checks — the company may be defunct; the idea
survives.

## 5. "Fleet-based AI that gets smarter" — what it means, how we build it

Their claim decoded: every deployed Glide uploads real-world sensor data
(especially safety-critical moments), models retrain centrally, better
weights ship back over-the-air to all devices — a **data flywheel**
(more devices → more data → better model → more sales). The $30/mo
subscription funds this loop. Full breakdown:
[[glidance-deep-dive-2026-08-20]].

**Our version at fleet-size 1** (cheap, real, portfolio-worthy):
1. The own-data capture loop already planned (auto-label → correct →
   nightly fine-tune) IS this flywheel.
2. **Log every intervention as a training label**: F8-hush, stumbles,
   overrides — save the surrounding 10 s of camera+ToF+IMU.
3. A "flag that" voice/tap bookmark for hard moments in the field.
4. Design the telemetry log format NOW (frames + ToF + IMU + what the
   system said + what you did) — that schema is what turns one helmet
   into a fleet later.

## 6. "The handoff document recently made"

Confirmed loaded: the session-continuation summary (made at compaction)
is in my context — Stage-4 state, wiring, standing rules, in-flight
agents, all of it. The repo's other handoffs (cad/MASTER-HANDOFF etc.,
08-16) are CAD-specific and unchanged. Nothing was lost.

## 7. Camera resolution for Apple-style signage (your instinct is right)

Already measured: the fisheye delivers ~16 px/° — a 15 cm sign character
is 8 px at 20 m (unreadable; need ~24–30 px). That's WHY the
implementation guide's #1 hardware call is a **second narrow (~38–50°)
global-shutter camera** — it reads text at 10–30 m, does the last-metre
fine guidance, and yes: signage needs OCR models (PARSeq, 15 ms/crop)
running alongside YOLO. All spec'd in
[[implementation-guide-2026-08-20]] + [[transit-headsign-ocr-2026-08-20]].

## 8. "Find Heinz" — your text-search idea is genuinely good

Logged in IDEA-BANK as **find-by-text**: user names a word, we run text
spotting over the video and beacon toward any hit. This sidesteps the
SKU database war entirely — no product catalog, just "does this word
appear in view." Realistic constraints: works at ~0.5–2 m on shelf
labels with the fisheye (farther with camera #2); needs the scanning
head sweep you'd naturally do. Same OCR stack as signage/labels — one
engine, three features (labels, signage, find-by-text).

## Logged decisions from this message

1. ✅ **Audio beacon** — adopt Soundscape's; deep-dive agent running.
2. ✅ **Queue detection + progress** — research/add (in IDEA-BANK §D).
3. ✅ **Empty-seat finding** — added; note the feasibility verdict
   recommends the "describe the seating" variant (bag-on-chair false
   positives) — your call after reading.
4. ✅ **Find-by-text** (Heinz) — new IDEA-BANK entry.
5. 🕐 **Person-following** — low priority ("demand seems thin") —
   matches the feasibility verdict.
6. ✅ **Apple-style signage reading** + OCR models alongside YOLO.
7. 🕐 **Route retrace (breadcrumb/teach-and-repeat)** — interesting,
   future, not #1.
8. **IDEA-BANK priority×impact rework — ordered.** First pass done: see
   the new PRIORITY VIEW at the top of [[IDEA-BANK]].
9. **Glidance**: adopt best features (list in
   [[glidance-deep-dive-2026-08-20]]); external research agent running
   on fleet-learning + independent reviews.

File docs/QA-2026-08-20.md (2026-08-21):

# Your questions answered + your decisions logged — 2026-08-20 evening

You asked for every unexplained term from the BLV reading in one doc. Here it
is, plus the decisions you made while reading, so nothing is lost.

---

## 1. The terms you asked about

**Aira** — a paid human-assistance service: a blind user opens an app and a
trained sighted agent sees their camera feed and talks them through anything
(reading mail, navigating an airport). It works extremely well and costs
**~$1.30–1.50 per minute** ($26/mo for 20 minutes). "Rationed emergency
resource" means users save it for crises because of the price — which is the
opportunity: anything we automate for free replaces rationed human minutes.

**Microsoft Soundscape** — the most-loved blind-navigation app ever shipped
(Microsoft killed it in 2023, then open-sourced it — we can read all its
design decisions in code, and we've adopted several: the 60 s no-repeat rule,
silence as the default state, volume used ONLY to signal confidence). Its
core feature was the **audio beacon**: a gentle repeating sound that seems to
come *from* your destination's direction through your headphones, so you walk
toward the sound instead of listening to "turn left in 20 meters."

**Entrance / doorway / last-meter / terminal guidance** — four names for one
problem. GPS gets a blind person to "you have arrived" — which means
somewhere within ~10 m of a building. Now they face 40 m of storefront: wall,
window, bike rack, planter, and one actual door, and the cane can't tell
which is which without trailing the whole facade. **"Last meter"** = that
final gap GPS abandons. **"Terminal guidance"** = our name for the fix:
the camera spots the door, the ToF confirms it's a real opening (depth
behind it) and gives exact range, and audio/haptics steer you to it — like
a plane landing on instruments. Same mechanic works for elevators, counters,
bus poles, seats.

**Queue detection and progress** — standing in line is genuinely hard blind:
where does the line end? Is it moving? Am I leaving a gap? Am I next? A
proven system (LineChaser, CHI 2021 — built on exactly our sensor combo,
camera + depth) finds the end of the line, tells you when the person ahead
moves ("line moved, step forward about two steps"), and says when you're at
the front. "Progress" = those move-up notifications.

**Empty seat finding** — walking into a waiting room / bus / lecture hall
and finding an unoccupied chair without touching strangers or asking. Camera
finds chairs, depth says which are empty (a person sitting there = a closer
return), guidance steers you. Blind users specifically listed this as a task
researchers ignore.

**The "social gap"** — the research shorthand for the interpersonal stuff
vision does at a party: who's in the room, where your friend is, whether
someone's approaching to talk, whether you're facing the person speaking.
Users called it their biggest pain ("I've lost count of the times I've ended
up talking to an empty chair"). The research verdict was that our sensors
serve it poorly EXCEPT empty-seat finding — but see your privacy decision
below, which reopens parts of it.

**SKU-level unwinnable** — SKU = one exact product ("Heinz ketchup 500 ml
squeeze bottle"). Recognizing *specific products* on shelves means keeping up
with ~30,000 NEW products per year, forever — a database war that even
grocery chains struggle with. **Aisle-level** ("cereal aisle", "dairy
section") needs only signs and categories — winnable. Reading a label
**in your hand** is also winnable (it's OCR, one product, close up) — and
you've now flagged that as a feature to add. ✅

**Person following ("walk with me")** — lock onto a chosen person (a friend,
a guide walking ahead) and give continuous bearing/distance so you can
follow them through a crowd without holding their arm — hands free for the
cane. Technically: ByteTrack already gives us per-person IDs; following = a
beacon on one tracked ID. The research called demand "thin" but the
precedent systems (BBeep, LineChaser) prove the tracking works. You asked to
hear more → queued for the new research pass.

**Standalone pedestrian detection** — announcing every person near you
("person left, person right, person ahead") as its own feature. Users
rejected THAT ("people see you coming and move; the dog walks around them").
It's noise. But people as *inputs* to other features — queue tracking,
person following, collision-course warnings — stay. That's the distinction.

**BuzzClip** (if you hit it in the reading) — a small clip-on ultrasonic
obstacle beeper. In the gold-standard trial it performed WORSE than a bare
cane and users rated it most frustrating: undifferentiated beeps = noise.
The cautionary tale behind our "informative or silent" rule.

---

## 2. Your decisions, logged (I build to these)

1. **Glass/touchscreen strategy: add a CV material detector** (glass/mirror
   segmentation — GDNet-B / RGB-D glass-detection literature already in our
   research). Lean on camera where ToF is blind. → added to IDEA-BANK as ✅.
2. **Label-reading-in-hand: add** as a feature candidate. ✅
3. **Compute is not a constraint.** Build for the future; use the GPU; a
   Jetson-Orin-class device is the eventual commercial target. Real-time on
   this laptop is the only bar. → unblocks heavier models (better seg,
   monocular depth, material detection).
4. **Head-height protection via geometry**: sensors sit ABOVE the head on the
   helmet; rule = keep **10–15 cm of clearance above the TOP ToF ray** to
   any overhead obstacle and the head provably can't hit anything. (Top ray
   of the 22.5°-down group ≈ horizontal, so this works as stated; sensors
   can tilt up ~1° on the ball mount if margin is thin.) → implement as an
   explicit "head-clearance" check on the top zone rows.
5. **Privacy/regulatory concerns: NOT a constraint right now.** Maximize
   research capability and impressiveness; features can be pulled back
   later. Facial recognition: *considering* — you lean "not necessarily
   useful" but it's not privacy-blocked anymore. (Noted: the research docs
   record the community's objections for whenever this goes public.)
6. **Terrain detection: do NOT cross out** — rocky/uneven terrain warning may
   be useful. Reopened for research (the earlier rejection was for flat-city
   walking where feet sense it).
7. **Currency detection: reconsider** — reopened.
8. **The cane is used alongside the device.** (Matches every research
   verdict; stays in all claims language.)
9. **Bone conduction: buy one** — affordable, on Amazon, fast shipping, easy
   to integrate (standard Bluetooth/3.5 mm). → buying-guide research queued.
10. **Crosswalk alignment: build-intent confirmed** → deep research queued.
11. **More research ordered** (agents launching): doorway/entrance guidance
    done RIGHT (how to make it as good as possible), head-height obstacle
    detection best practice, bus/route-number + public transport assistance
    generally **including getting into cars/rideshares**, dropped-object
    finding feasibility (can our resolution see small objects on the floor —
    math + evidence), empty-seat state of the art, person-following.

## 3. Corrections/notes on your geometry point

One nuance on "ToFs are currently 0°": the pair is group-tilted 22.5° DOWN
(CAD-verified), so the grid spans from ~0° (top row edge ≈ horizontal) to
~45° down. Your safety rule still holds — the TOP ray is the head-clearance
ray — but the margin math must use the top-row zone rays specifically, and
the ball mount means the leveling step (voice-guided, key `l`) is what
guarantees the top ray really is horizontal on any given day.

## 4. Where everything else lives

- Triage table: [[IDEA-BANK]] (your ✅/❌ marks go there)
- Reading order for the rest: [[READ-ME-TODAY-2026-08-20]]
- The strategy: [[UTILITY-ROADMAP]]

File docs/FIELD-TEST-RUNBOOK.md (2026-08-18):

# Field-test runbook — backpack rig — 2026-08-18

The rig: laptop in backpack running `cv_fusion.py`, helmet ESP32 + USB camera
cabled to it, wired earbuds from the laptop, phone as the pocket display.

## One-time setup (at home)
1. **Windows Mobile Hotspot ON** (Settings → Network → Mobile hotspot).
   Note the hotspot name/password; the laptop's IP on its own hotspot is
   always **192.168.137.1**.
2. Phone: join the laptop's hotspot. Bookmark **http://192.168.137.1:8090/**.
3. Plug in: helmet USB (ESP32), camera USB, earbuds. Screen can be closed *if*
   power settings say "do nothing on lid close" while on battery — check.

## Launch (before it goes in the backpack)
```
cd C:\esp-projects\vl53l8cx_esp32\camera
python cv_fusion.py --source helmet --serial --port COM9
```
`--serial` = ToF+IMU over the USB cable — **no home WiFi needed anywhere**.
The console prints the phone-viewer URL. Open it on the phone: full annotated
view (zones, boxes+ranges, horizon, attitude inset) at ~10 fps.

## Pre-walk checks (2 min)
- [ ] Phone shows the live view and it follows head motion
- [ ] Voice speaks in the earbuds (walk at a wall — "obstacle, ahead")
- [ ] Ticker audible but not drowning speech
- [ ] Physical pause switch kills the motors (flip test)
- [ ] Press `l` on the laptop first if the ball mount needs leveling
      (voice-guided), or run it by feel

## During the walk — what to collect
- Snapshot key moments from the PHONE (screenshot) — misdetections, missed
  obstacles, wrong ranges; each becomes a labelled test case
- Note every false alert and every miss with rough time; the DEVLOG wants
  Problem→Root cause pairs
- Try: doorway, head-height branch/sign, glass door (expect a miss — that's
  the known ToF limit, film it for the demo), thin pole, stairs approach
- Note battery %, any thermal slowdown, any USB dropout ("sensors lost"
  callout = the stream died)

## Known limits going in
- Sunlight cuts ToF range to ~1–1.5 m (indoors/overcast for the first walks)
- Camera↔ToF latency misregisters during fast head turns (de-rotation is on
  the backlog) — scan slowly for now
- imu_mount_cal not run ⇒ horizon/attitude labels may be rotated until it is

## Wishlist discovered by this runbook
- Run on the second laptop instead (lighter backpack) — pull the repo there,
  `pip install ultralytics opencv-python pyserial pyttsx3 pygrabber scipy`,
  same launch line. Spec check pending (machine was unreachable 2026-08-18).

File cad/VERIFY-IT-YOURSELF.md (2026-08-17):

# Verify it yourself — every number I gave you, checked in SOLIDWORKS

Don't take any of the figures below on trust. Each one has a procedure next to it.
If your measurement disagrees with mine, **your measurement wins** — tell me and I'll
find my mistake.

Everything I computed came from `cad/solidworks/doubleTOFassem.STEP`, the file you
exported at 16:57 on 2026-08-04. The script is `cad/check_user_assembly.py`.

---

## FIRST — a correction about which axis is "vertical"

You asked about "the same vertical coordinate in the **z-axis**". In your model,
**vertical is Y, not Z.**

**How I know, and how you can check:** I computed the downward pitch two ways.
Treating Y as vertical gives **exactly 22.50°** for both boards — the number you
designed to. Treating Z as vertical gives 67.5°, which is nothing you ever asked
for. Only one of those can be right.

**Check it in SOLIDWORKS:**
1. Look at the little origin triad in the bottom-left corner of the graphics area.
2. Press **Ctrl+7** (Isometric), then **Ctrl+1** (Front).
3. In Front view, the axis pointing **up the screen** is the vertical one. Read its
   label off the triad.

SOLIDWORKS' default Front Plane is the XY plane with **Y up** — which is why it
came out this way. This matters because if you go set the camera's height using a
Z coordinate, you'll move it sideways instead of up.

---

## 1. Are both ToF sensors at the same height? — **YES, exactly**

| | |
|---|---|
| Board A optical centre | (670.045, **294.917**, 1522.646) |
| Board B optical centre | (704.789, **294.917**, 1508.529) |
| Vertical difference | **0.000 mm** |

**Check it yourself:**
1. **Evaluate → Measure**.
2. Click the **top face of the VL53L8CX chip** on board A (the small 6.4 × 3.03 mm
   package near one end — zoom right in, it's the only thing that shape).
3. Ctrl-click the same face on board B.
4. In the Measure box, click the **arrow/dropdown next to the distance readout** and
   turn on **Delta X / Delta Y / Delta Z**.
5. **Delta Y should read 0.00 mm.** Delta X and Delta Z will not be zero — that's
   the 44° splay, and it's correct.

*Why I used the chip's top face:* that's the aperture plane — the surface light
actually enters. Measuring from the PCB instead would be off by 1.75 mm + half the
board thickness.

---

## 2. Pitch — **22.50° down, both boards**

**Check it yourself:**
1. **Evaluate → Measure**.
2. Click the **top face of the VL53L8CX chip**.
3. Ctrl-click the **Top Plane** in the feature tree (expand the assembly's top node
   if you can't see it; if it's hidden, right-click → Show).
4. Read the **Angle** value. It should be **22.50°**, or its complement 67.50°
   depending on which normal SOLIDWORKS picks — both mean the same thing.

Do it for both boards. They should match to two decimals.

---

## 3. Yaw splay — **44.00° between the two, i.e. 22.00° each**

**Check it yourself:**
1. **Evaluate → Measure**.
2. Click the VL53L8CX top face on board A.
3. Ctrl-click the VL53L8CX top face on board B.
4. Read **Angle**: **44.00°**.

That is the *total* angle between them, so each sits 22.00° off the centreline —
exactly what you set. ✓

---

## 4. Baseline between the sensors — **37.50 mm**

**Check it yourself:** same Measure, two chip top faces, read **Distance**
(not Delta) → **37.50 mm**.

⚠️ **This is 3.5 mm wider than the 34 mm in `DESIGN-REFERENCE.md`.** Not an error —
just a consequence of how your slots ended up spaced. The one thing it changes:

**The blind corridor dead ahead closes at 2.15 m instead of 1.95 m.** Between the
sensor and 2.15 m there is a narrow strip straight in front that *neither* ToF
covers. The camera still sees it; it just has no measured distance there.

If you want that back to 1.95 m, bring the two boards 3.5 mm closer together.
I'd leave it — 20 cm of difference in where the corridor closes doesn't change
anything you'd actually notice.

---

## 5. Apertures — **clear, but the test is not yet meaningful**

The 45° cone from each sensor hits **0.000 cm³** of your plastic. But look at *why*:

> nearest plastic to the optical centre: **8.27 mm**

The sensors are looking out into open air. **There is no front wall in front of them
yet** — your three printed bodies are the slot/rail carriers, sitting beside and
behind the boards, not in front. Nothing can obstruct a view when nothing is there.

So: **no aperture problem today, and no aperture verified either.** The moment you
add a front face with a window in it, re-run `python cad/check_user_assembly.py`
and it becomes a real test.

**When you do cut that window, the size it needs is:**

opening = 1.0 mm + 2 × depth × tan(22.5°) = **1.0 + 0.83 × depth**

| Recess depth behind the outer surface | Minimum opening | With 1 mm tolerance |
|---|---|---|
| 2 mm | 2.66 mm | 4.66 mm |
| 4 mm | 4.31 mm | 6.31 mm |
| 6 mm | 5.97 mm | 7.97 mm |
| 10 mm | 9.28 mm | 11.28 mm |

**Check your own version in SOLIDWORKS:**
1. **View → Display → Section View**, pick a plane through the sensor centre.
2. **Measure** from the chip's top face to the wall's **outer** face → that's *depth*.
3. **Measure** the hole across the **outer** face — the outside, not the inside. A
   straight bore is narrowest where it starts.
4. Compare against the table.

---

## 6. Fit — ⚠️ **0.080 mm at two spots**

### Which parts, exactly

They are **not** SMD chips — I was imprecise. They are the **black plastic bodies of
the two 0.1" pin headers** on the **back** of the board (the side away from the ToF
chip). Measured in board-local coordinates:

| | Header 1 | Header 2 |
|---|---|---|
| Along the 51.5 mm length | 0.49 → 28.55 mm | 30.97 → 38.71 mm |
| Length | 28.07 mm (11 pins × 2.54) | 7.75 mm (3 pins × 2.54) |
| Across the 19.5 mm width | 16.98 → 19.52 mm | 16.98 → 19.52 mm |
| Below the PCB back face | 0.10 → 2.64 mm | 0.10 → 2.64 mm |
| **Gap to your plastic** | **0.080 mm** | **0.080 mm** |

Both hug the **same long edge** (the W≈19.5 side) and both hang **2.64 mm below the
board**. Identical on both ToF boards, which makes sense — same part, same slot.

The metal pins go a further 10.06 mm down and are separate solids; they're not the
pinch. It's the plastic shroud.

### What's actually happening

Your 1 mm margin is measured off the **PCB outline**, and against the PCB it's
holding perfectly — 1.000 mm all round, exactly as designed. ✓

The problem is that the header shroud **sticks out past the PCB in a direction your
outline offset never accounted for**: down, off the back face. Your slot floor
passes under the board and arrives 0.080 mm from those shrouds.

So this isn't a mistake in your margin. It's a feature the margin doesn't cover.

### Why 0.35 mm — and you're right to push back

0.35 mm is **not a universal number**. It's the figure for *one specific case*: a
sliding fit on FDM. Here's where it comes from:

| Source of error | Typical size |
|---|---|
| FDM dimensional accuracy | ±0.10 – 0.20 mm |
| Elephant's foot (first layers squish out) | 0.05 – 0.15 mm |
| Extrusion width overshoot on inside corners | 0.05 – 0.10 mm |
| **Realistic worst case stack-up** | **~0.3 mm** |

0.35 mm isn't "space I want" — it's "the amount the print will differ from the model."
At 0.080 mm nominal, a normal-quality print lands you at **negative** clearance:
the faces touch, and the board won't slide in.

**The number changes with the process and the job:**

| Situation | Clearance |
|---|---|
| FDM, sliding fit (this one) | 0.30 – 0.40 mm |
| FDM, press fit / never moves | 0.10 – 0.20 mm |
| Resin (SLA/MSLA), sliding | 0.10 – 0.15 mm |
| Resin, press fit | 0.05 mm |

**So the honest answer:** if you're printing resin, 0.15 mm is enough and 0.080 is
still slightly too tight. If FDM, you want 0.3 mm+. Either way 0.080 is under the
line — but by much less than my first message implied.

And note this is a **slide-in** joint down the board's full length. Clearance that
would be fine on a face that just sits there has to hold over 28 mm of travel here.

### How to measure it yourself

**Evaluate → Clearance Verification** — this is the right tool, not Interference
Detection. Interference only finds solids that actually *overlap*; yours don't, they
just come close, so Interference Detection reports nothing and you'd think you're fine.

1. **Evaluate → Clearance Verification**
2. **Selected items**: click the SATEL board, then Ctrl-click your slot part
3. **Acceptable clearance**: type **0.35** (or whatever you settle on above)
4. **Calculate**

Everything it lists is *closer than* your threshold. Click each result and it
highlights the two faces in the graphics area, so you can see exactly where.

**To measure one spot by hand instead:** **Evaluate → Measure**, click the header's
outer face, Ctrl-click your slot's inner face, read **Distance**. Set the dropdown to
**Minimum Distance** — the default centre-to-centre reading is not what you want here.

### The fix

Don't widen the whole slot — you'd lose the location accuracy the 1 mm outline is
giving you. Instead **cut a local relief pocket** where the two shrouds run:

- along the length: **0 → 39 mm** (covers both, with a bit of run-out)
- across the width: the **16.5 → 20 mm** band
- depth: **0.5 mm** into your slot floor

The PCB outline keeps doing the locating; the headers just get somewhere to go.

---

## 7. Camera height above the ToF — **3–5 cm is fine**

Full numbers: `python docs/camera_height_offset.py`

**The counter-intuitive part:** parallax is *not* an error. It's a fixed geometric
constant. Stage 3 measures it once, and the fusion maths removes it exactly. A 50 mm
offset measured to ±2 mm is **exactly as accurate** as a 10 mm offset measured to
±2 mm — 1.3 px of residual at 1 m either way. Offset size doesn't degrade anything.

What the offset *does* cost, and both are small:

| Offset | ToF fan fully in frame beyond | Occlusion band at 0.5 m |
|---|---|---|
| 30 mm | 0.19 m | 6 mm |
| 50 mm | 0.31 m | 10 mm |
| 80 mm | 0.50 m | 16 mm |

At 50 mm, everything past 31 cm is fully covered — closer than the sensor's useful
warning range anyway.

**What actually matters, in order:**
1. **Rigidity.** If the camera shifts 1 mm relative to the ToF after you calibrate,
   that hurts more than a 50 mm offset ever will. Build it stiff.
2. **Solve the offset in the Stage 3 calibration**, don't trust a ruler.
3. **Keep both at the same 22.5° pitch.** That's what centres the ToF band in the
   frame with symmetric 9.06° margins.

**So: put the camera wherever the mount is stiffest and the wiring is cleanest.**
Height is not the constraint you thought it was.

**Check the margin claim yourself:** the camera's vertical view is 63.12°
(measured, `camera/calibration_720p.txt`), the ToF's is 45° (ST DS14161 Table 2).
Both pitched 22.5°. (63.12 − 45) / 2 = **9.06°** spare each side. Frame-exit
distance = offset ÷ tan(9.06°) = offset ÷ 0.1595.

---

## 8. Getting the fields of view into YOUR assembly

**What went wrong the first time:** I exported the whole thing — your two ST boards,
your three printed bodies and both cones — as one 22 MB nested STEP. SOLIDWORKS
opened it as an **empty assembly**. The file is fine (I re-imported it: 239 solids,
all present), the importer just didn't swallow it. Pressing F did nothing because
there was genuinely nothing there to zoom to.

**The better route** — put the cones into the assembly you already have:

| File | Size | Use |
|---|---|---|
| `step\USER_REF_fov_A.step` | 344 KB | insert into your assembly |
| `step\USER_REF_fov_B.step` | 331 KB | insert into your assembly |
| `step\USER_assembly_at_origin.step` | 23 MB | fallback, everything, moved to origin |

The two cone files carry **absolute coordinates**, so they land on their sensors
exactly — no mating, no alignment.

**Do this in the COPY, not your working file.** There is now an isolated copy at:

```
cad\solidworks\fov_review\doubleTOFassem.SLDASM
```

Every part it needs was copied alongside it, plus both cone files. Your real
`cad\solidworks\doubleTOFassem.SLDASM` is untouched (still stamped 01:21 AM).

⚠️ **One caveat:** SOLIDWORKS stores reference paths inside the assembly, so the copy
may still load the *original* part files rather than the ones sitting next to it.
That's harmless **as long as you only insert components and never edit a part inside
this copy** — inserting changes the assembly file only, and the assembly file is the
copy. If you want to edit geometry, do it in your real file.

**Click by click:**

1. Open **`fov_review\doubleTOFassem.SLDASM`** (the copy — already opening).
2. **Insert → Component → Existing Part/Assembly**
3. **Browse** → set the file-type dropdown to **STEP (\*.step;\*.stp)** → pick
   `USER_REF_fov_A.step`
4. ⚠️ **Click the green ✓ in the PropertyManager. Do NOT click in the graphics area.**
   Clicking in the graphics area drops it wherever your cursor was. The ✓ places it
   at the assembly origin, which is what preserves its absolute position.
5. Repeat for `USER_REF_fov_B.step`.

**Make them see-through:** right-click the component → the **beach-ball
(Appearances)** icon → **Transparency** slider to about 70%.

**Make them reference-only** (this is the "ghost part" you asked about):
right-click the component → **Component Properties** → tick **Envelope**. An envelope
component is reference geometry by SOLIDWORKS' own definition — excluded from the
BOM, excluded from mass properties, and never treated as a real part. That is the
built-in version of what you described.

**Sanity check that they landed right:** the cone's sharp tip should sit exactly on
the ToF chip's top face. If it's floating in space, you clicked in the graphics area
at step 4 — undo and use the ✓.

---

## Re-running the whole check

```
python cad/check_user_assembly.py
```

Re-export the STEP from SOLIDWORKS first (**File → Save As → STEP**, same filename),
then run it. It writes `cad/step/USER_doubleTOFassem_FOV.step` — your assembly with
the 45° fields of view attached to each sensor as wireframe cones, nested inside the
sensor nodes so they move together. They're named `REF_fov_*` and are never printed.

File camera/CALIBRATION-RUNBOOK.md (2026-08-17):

# STAGE 2 — Calibrate the camera (morning runbook)

Everything is written and syntax-checked. Follow top to bottom. ~30 min, most of it printing and waving a board around.

**Prerequisite from Stage 1:** the lens barrel is focused and **locked** (nail polish / Kapton), with a witness mark drawn across the joint. If it isn't locked, do that first — recalibration is the price of skipping it.

---

## 1. Print the board (5 min)

File: `camera/checkerboard_8x11_20mm.pdf`

- Print **at 100% / "Actual size"**. **Not** "Fit to page" / "Shrink to fit" — that silently resizes the squares and every measurement downstream is wrong.
- **Matte paper only.** Glossy reflects and the corner detector fails on the glare.
- **Verify with a real ruler:** the printed scale bar must measure **exactly 100 mm**. If it doesn't, reprint. (If your printer can't do it, measure the bar and tell me — I'll adjust `SQUARE_MM` instead.)
- **Glue it to something rigid and flat** — foam-core, clipboard, stiff cardboard. **Flatness matters more than print quality.** A curled page bends the geometry the whole method assumes is flat, and no amount of extra images fixes that.

One sheet is enough. You'll move it around rather than print several.

## 2. Capture the images (10–15 min)

```
python camera/capture_calib.py
```

Hold the board up and move it around in front of the camera.

- Green overlay on the corners = detected.
- It **auto-captures** when the board is found, held still, and in a screen region not yet covered. Green flash = saved. SPACE forces a capture.
- **Coverage grid, 3×3 in the corners of the view.** Red = 0 shots, orange = 1, green = 2+. **Get all nine green.** The edge and corner cells are what pin down the fisheye distortion — the centre alone gives a model that's guessing out at the rim.
- **Vary the tilt a lot.** Steep angles, rotations, both directions. **Flat-on square-to-the-camera shots are the useless ones** (see below).
- **Vary the distance** — board filling most of the frame, and small in a corner. The readout shows what fraction of the frame it fills.
- Target **20+ keepers**, all nine cells green. Press `q` when done.

Keys: `SPACE` force-capture · `d` delete last · `r` reset · `q` finish

## 3. Calibrate (30 seconds)

```
python camera/calibrate_fisheye.py
```

Reads the images, fits the lens model, writes:
- `camera/calibration_720p.npz` — **K and D, the actual deliverable**
- `camera/calibration_720p.txt` — readable report, includes the **measured** FOV
- `camera/undistort_preview.jpg` — before/after, to eyeball

**Judge it by the RMS reprojection error:**

| RMS | Meaning |
|---|---|
| **< 0.5 px** | Good. Use it. |
| 0.5–1.0 px | Usable. More/steadier views would improve it. |
| > 1.0 px | Something's wrong — board not flat, focus shifted, blurry frames. |

Per-image errors are printed worst-first. One bad frame dragging the fit is easy to spot: delete it from `camera/calib_shots/` and re-run.

Open `undistort_preview.jpg` — in the right-hand image the board edges should be **straight**.

## 4. Tell me the numbers

Send me the RMS and the measured HFOV/VFOV. That's the first time we'll have **real** field-of-view numbers instead of the extrapolated ~109°/67° guess.

Then we go to **Stage 3 — ToF-camera alignment (extrinsics)**, and then **Stage 4, the actual fusion overlay.**

---

## Why any of this works (the part worth understanding)

We know the board's real geometry exactly: a flat grid of 20 mm squares. So for each photo OpenCV can ask: *given that this known flat grid landed on these particular pixels, where was the camera and what must the lens be doing to light?*

One photo leaves too many unknowns. Many photos of the **same** board from **different** angles over-constrain the problem until only one lens model fits them all. That model is **K** (focal length in pixels + true optical centre) and **D** (how the lens bends light outward). This is **Zhang's method**.

**Why tilting is required, not a problem.** Held flat-on and square, "small board close" and "big board far" produce nearly identical images — focal length and distance trade off and can't be separated. Tilting breaks the tie: a tilted plane foreshortens in a way that depends on focal length *alone*. **Tilt is what makes the answer unique.**

**Why `cv2.fisheye`.** The standard pinhole model assumes a ray at angle θ lands at `f·tan(θ)` from centre. At 140° `tan(θ)` blows up and the fit fails or skews badly. The fisheye (Kannala-Brandt) model uses θ directly plus four correction terms and stays well-behaved to the edge. Rule of thumb: **above ~120°, use fisheye.**

**Videos, if you want them first:**
- Cyrill Stachniss — *Intrinsic Camera Calibration* (5 min): https://www.youtube.com/watch?v=26nV4oDLiqc
- Cyrill Stachniss — *Zhang's Method*: https://www.youtube.com/watch?v=-9He7Nu3u8s

---

## Notes
- All capture is at **MJPG 1280×720**. 1080p is unusable on this module (firmware bug — `docs/datasheets/camera/HBV-1716WA-VERIFIED-SPECS.md`). **K is resolution-dependent** — change resolution and this calibration is void.
- If the module gets too hot to hold a finger on, unplug and let it cool. Above ~50 °C the OV2710 leaves its stable-image band (datasheet Table 8-2), (The earlier USB drop-outs were manual unplugs, not a fault - resolved 2026-07-31.)
- We do **not** undistort the image for fusion. The preview is only a sanity check. Fusion keeps the raw fisheye frame and projects ToF zones into it with `cv2.fisheye.projectPoints` — wastes no field of view, resamples nothing.

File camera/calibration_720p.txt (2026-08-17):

HBV-1716WA fisheye calibration  (1280x720, MJPG)
images used : 19
board       : 8x11 inner corners, 19.6 mm squares
RMS reprojection error : 0.3006 px   -> GOOD - use it

K =
[[669.8228   0.     620.9529]
 [  0.     670.0752 335.1691]
 [  0.       0.       1.    ]]

D (k1..k4) =
[-0.079359 -0.006644  0.016116 -0.007523]

fx = 669.823 px    fy = 670.075 px
cx = 620.953 px    cy = 335.169 px      (frame centre would be 640.0, 360.0)

MEASURED field of view (this replaces the extrapolated ~109/67 guess):
  horizontal 119.58 deg
  vertical    63.12 deg
  diagonal   144.02 deg   (box claims 140 deg diagonal)

per-image mean error (px):
   0.554  calib_008.png
   0.431  calib_009.png
   0.252  calib_012.png
   0.213  calib_013.png
   0.210  calib_011.png
   0.196  calib_015.png
   0.181  calib_016.png
   0.166  calib_006.png
   0.163  calib_001.png
   0.139  calib_014.png
   0.138  calib_002.png
   0.137  calib_000.png
   0.133  calib_018.png
   0.129  calib_005.png
   0.126  calib_019.png
   0.126  calib_017.png
   0.116  calib_010.png
   0.112  calib_004.png
   0.103  calib_003.png

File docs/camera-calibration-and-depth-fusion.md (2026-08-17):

# Camera Calibration, Dewarping & Depth↔Pixel Fusion — Research Reference

**Created 2026-06-08.** Companion to `camera-and-multisensor-layout.md`. Covers (A) how to
calibrate + dewarp the 140° HBV-1716WA, and (B) the state of the art in fusing sparse
distance data (ToF) onto camera pixels. **Consult before writing the calibration or fusion code.**

---

## PART A — Calibrating & dewarping the 140° wide camera

### A1. Which distortion model? → **FISHEYE (Kannala-Brandt), not pinhole**

Our lens is **140° diagonal** — exactly the boundary where the standard model fails:

- **Standard pinhole** (`cv2.calibrateCamera`, radial+tangential k1,k2,k3,p1,p2): designed
  for narrow/normal lenses. On a 140° barrel-distorted image it gives **poor results or
  fails** — it can't model the extreme edge distortion, and undistorting throws away a lot of FOV.
- **Fisheye / Kannala-Brandt** (`cv2.fisheye`, 4 coeffs **k1,k2,k3,k4**): purpose-built for
  wide/fisheye lenses. Sources agree it's the right pick for **≤140° diagonal FOV**.
- **Verdict: use `cv2.fisheye`.** We're at the top of its sweet spot.

(If a calibration ever comes out poor, the fallback ladder is: fisheye → omnidirectional
`cv2.omnidir` (for >180°) — but we won't need that at 140°.)

### A2. Calibration target → **ChArUco board** (not plain checkerboard)

ChArUco = checkerboard + ArUco markers in the white squares. Why it beats a plain checkerboard
**for a wide lens specifically**: it still works when **part of the board is occluded or off-frame
or edge-distorted**, because each marker is uniquely identified — so you can fill the *corners*
of a 140° frame (where distortion is worst and a plain board is hardest to fully capture).
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

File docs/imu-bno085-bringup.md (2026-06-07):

# BNO085 IMU bring-up (Phase 3 head-orientation)

Verified working **2026-06-03** on a bench ESP32‑C6 + GY‑BNO08X board, streaming drift‑free
absolute orientation. This is the foundation for **Phase 3 sensor fusion** — fusing the
VL53L8CX distance grid with head orientation so obstacle directions can be mapped into a
stable world/body frame instead of "wherever the head happens to be pointing."

> Bring-up was done on a **C6** (separate project: `C:\esp-projects\mpu6050-c6\`). The
> helmet runs on the **ESP32‑S3** — the config below is correct, but **GPIO pins must be
> reassigned** for the S3 (see "Integration plan").
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

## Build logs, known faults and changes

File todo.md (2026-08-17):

# Helmet project — TODO

Living list of work for this project. Append-only during sessions; check items off only after they're done AND verified.

## Active request queue (2026-06-07 — work ONE at a time, confirm before next)

Per Reuben's workflow rule: log every request here BEFORE starting, do ONE, report+confirm, then raise the next. He dumps ideas as they come; we work them sequentially, no multitasking.

- [x] **A. Visualizer 1 FPS regression.** RESOLVED — was stale TCP clients + ESP brownout, AND the `FREERTOS_HZ=100` bus-starvation bug (see 2026-06-08 below). After the FREERTOS fix the viz holds a steady 16 FPS on a clean boot.
- [x] **B. Green LED meaning.** Firmware drives NO status LED — the green LED is a BOARD indicator (serial-TX / USB-JTAG activity), not firmware. Confirmed.
- [ ] **C. CV-robotics course catch-up.** Untouched since the first ToF install. Review where he left off (`C:\claude-projects\cv-robotics-course\BRIEFING.md`) + what to go over. (TaskList has Module 0/5/3 pending.)
- [ ] **D. ToF↔ToF interference — DECISION.** Research done: largely a NON-ISSUE for this geometry (~35° apart; histogram rejects cross-light as ambient noise, not phantom targets); ST's SYNC pin is the first-party fix if ever needed. Optional 10-min A/B test (log `target_status` + sigma with the other sensor ON vs OFF at <60 cm). Decide whether to bother.
- [ ] **E. 3D-viz approach — DECISION.** Research done: recommend switching the viz to **Rerun** (rerun.io) — purpose-built for streamed sensor + transform-tree + recording/playback; deletes the hand-rolled render loop/threads/transforms. ~1–2 sessions; keep PyQtGraph until Rerun reaches parity. Decide: pivot vs. keep refining PyQtGraph.
- [ ] **F. Visualizer refactor to best practices** — folds into E (Rerun) or hardening PyQtGraph (latest-frame handoff already present; reconnect + exception isolation improved 2026-06-07).
- [x] **G. IMU yaw drift.** DONE (2026-06-08). Empirically A/B-tested the magnetometer: the haptic motors corrupt it (mag accuracy High→Low, ~60° yaw jumps) at ~5 cm spacing → went **mag-free `SH2_ARVR_STABILIZED_GRV`**. Added gyro-ZRO + accel calibration (`sh2_setCalConfig`) and DCD persistence (`sh2_setDcdAutoSave`). Dynamic drift +2.24°→+0.82° (~63%). Recenter button = north substitute. Full RCA in `docs/DEVLOG.md`. **Open follow-ups:** confirm drift gain with 2+ more `after_levers` runs (N=1 so far); verify DCD-persistence across a power cycle.

**Researched 2026-06-08 (evening) — Phase 2/3 sensor suite (full writeup: `docs/camera-and-multisensor-layout.md`):** Camera HBV-1716WA/OV2710 datasheets downloaded (`docs/datasheets/camera/`). Key findings: WA lens = 140° **diagonal** → extrapolated **HFOV ~109° / VFOV ~67°** from HBVCAM's lens ladder (CALIBRATE to confirm); **1080p is MJPEG-only** (YUY2 maxes at 640×480); OV2710 is **rolling shutter**. ToF↔ToF interference **properly researched** (was overstated before): real for dToF generally, but L8CX = noise-floor + `target_status`-flagged, NOT phantom obstacles; fix = edge-to-edge or temporal stagger. New **two-ToF layout** designed: each sensor **22.5° off-center (45° apart) = 90° H**, tilted **22.5° down** (FoV 0° to −45°), + HC-SR04 ultrasonics for overhead/near-low gaps. **This left/right design supersedes the top-up/bottom-down build (item below) — still a proposal, not built.** Open: ultrasonic placement (1up+1down rec.), camera calibration, max-overlap-vs-max-coverage aiming decision. **Calibration + depth↔pixel fusion also researched** (`docs/camera-calibration-and-depth-fusion.md`): 140° → use `cv2.fisheye` (Kannala-Brandt) + ChArUco, NOT pinhole; for fusion keep raw image + `fisheye.projectPoints` the 64 ToF zones via measured extrinsics; skip depth-completion nets (overkill at 64 pts) → projection + detection-gating. Leaders surveyed (KITTI completion, BEVFusion/PointPainting, Apple/RealSense). **Round 2 (3 research agents, `docs/camera-compute-and-fusion-options.md`):** (1) **Compute host** — ESP32-S3 can't host the cam (Full-Speed USB → VGA); rec = laptop dev → **Pi 5 + Hailo-8L (~$130/10 W, YOLOv8s 25–35 FPS)** as vision brain, S3 stays reflex/haptic. (2) **Fusion progression** A overlay+reflex → B detection-gating → C mono-depth+ToF-anchor (Depth Anything → dense metric depth over full 140°); skip generic completion nets. (3) **UM3109-VERIFIED CORRECTIONS:** VL53L8CX **HAS a dedicated SYNC pin (B1)** for multi-sensor interference (`vl53l8cx_set_external_sync_pin_enable`, §4.15) — the real dual-ToF fix; **no dedicated interference flag** (degrades to low-conf `target_status`, only 5=100% valid); OV2710 rolling-shutter confirmed; 140°=diagonal confirmed.

**Shipped this session (2026-06-08):** IMU yaw-drift resolved end-to-end — magnetometer A/B test → **mag-free AR/VR-Stabilized GRV** decision (motors corrupt the mag: High→Low accuracy, ~60° jumps); found + fixed the **`FREERTOS_HZ=100` bug** (IMU task's 2 ms delay rounded to 0 → spun → starved the ToF loop on some boots = the old "~20% warm-reboot flake") by setting it to 1000; added **gyro-ZRO + accel calibration + DCD persistence**; dynamic drift +2.24°→+0.82°. Decoupled `Q:` from the ToF frame gate. New test tools: `imu_capture.py`, `imu_drift_dynamic.py`. Full RCA in `docs/DEVLOG.md`.

**Shipped 2026-06-07:** BNO085 IMU fully working at ~100 Hz on the shared I²C bus alongside both ToF sensors — three stacked bugs fixed (wrong addr → **0x4A**; missed one-time SHTP advertisement → **soft-reset** in `hal_open`; hub starvation during ToF firmware upload → **bring IMU up after ToF init + dedicated 500 Hz task + mutex**). `Q:` quaternion integrated into the visualizer (head-attached geometry rotates with orientation; "Recenter IMU" button). Full RCA in `docs/DEVLOG.md`. Fixed a viz `NameError` (`side`→`self.side`) + exception isolation on the IMU path.

## In progress (no active items — see Queued)

## Recently shipped (2026-05-25 → 2026-05-28)

- [x] **Rotation in firmware:** `MOUNT_ROTATION_DEG = 270` confirmed working in `main.c`, applied via `rotated_zone()` helper to all three stream functions (DATA/SIGMA/STATUS). Single source of truth at the chip — all downstream consumers see body-frame data automatically.
- [x] **README first-person rewrite + v9 photos + Limitations subsection.**
- [x] **Helmet-mount tilt calibration via wall stare** (2026-05-25). Pitch 13° → 20° after physical mount adjustment. `visualizer/calibrate_tilt.py` + raw captures in `visualizer/raw_frames/wall-tilt-calib-h185cm-d81cm_*.csv`.
- [x] **Per-row slant compensation in firmware** (shipped). `MOUNT_PITCH_DEG = 20.0f`, `compute_row_cos_table()` runs at boot, nearest-distance loop multiplies slant by `g_row_cos[row]` before comparing to per-row thresholds. Raw `DATA:` stream is unaffected (still slant) so analysis tools see what the sensor sees.
- [x] **Per-row alert thresholds** in firmware (60/60/80/95 cm at 4×4 — innovation, not from literature).
- [x] **Urgency-ratio buzzer** — beep rate scales with `forward / row_threshold` (ratio²) instead of absolute distance. Lower-row obstacles beep faster at the same forward distance because their FoV exits sooner.
- [x] **30 Hz ranging at 4×4** (bumped from 20 Hz after wearable-latency research; latency dominates per-zone noise by 10–40× for a moving user — see `docs/research-optimal-config.md`).
- [x] **OTA bug RCA closed** (2026-05-26): verbose UART logging throttling OTA to 15 KB/s. Fixed by reverting to INFO log level. Now 164 KB/s.
- [x] **Phase 2A/B/C/D research synthesis** (`docs/research-optimal-config.md`): ST docs deep-dive, academic literature review, market survey, with source-verification appendix retracting fabricated AN5912/AN6066/ETH-median-filter citations.
- [x] **Below-chest coverage research** — three options documented (move sensor lower / two-sensor stack / multi-row ultrasonic). Hybrid path = preferred.
- [x] **Haptic motors bench-tested** (2026-05-26 single motor, 2026-05-28 all 3). Driver: 2N3904 NPN low-side switch + 1 kΩ base resistor per motor. GPIO 7/15/16, LEDC ch 1/2/3 timer 1 @ 1 kHz.
- [x] **Haptic motor physical-position mapping VERIFIED** (2026-05-28) via single-pin OTA pulse test (`HAPTIC_ID_MODE`):
  - **GPIO 7  = CENTER (forehead)**
  - **GPIO 15 = RIGHT temple**
  - **GPIO 16 = LEFT temple**
  - Aliases `HAPTIC_GPIO_CENTER` / `_RIGHT` / `_LEFT` in `main.c`.
- [x] **Safety GPIO boot config** — all 3 motor GPIOs forced OUTPUT-LOW with pulldown at the very start of `app_main` regardless of `HAPTIC_TEST` state. Prevents stuck-on motor after warm reboot.
- [x] **Directional-haptics research with primary sources** (2026-05-28) — full citations in `docs/research-sources/directional-haptics-mapping.md`. Verifies that concurrent multi-motor firing is precedented (GuideTouch), squared PWM curve is supported for alerting (Stevens' law), funneling isn't an issue at our motor separation (Kaul 2020), and dominance weighting is warranted (Zegarra Flores 70% finding).
- [x] **Directional column→motor haptic drive IMPLEMENTED** (2026-05-28). `ranging_task` maps obstacle columns to LEFT/CENTER/RIGHT motors each frame: hard regional mapping + per-motor most-urgent tracking + squared duty curve + dominance weighting. `haptic_motors_init()` runs at boot in sensor mode; LEDC infra pulled out of `#if HAPTIC_TEST`. Bench-confirmed. **ERM dead-zone fix:** added `HAPTIC_DUTY_MIN` (130) floor so an alerting motor is felt the instant the buzzer fires instead of staying silent until ~20 cm. New knobs: `HAPTIC_DIRECTIONAL`, `HAPTIC_DUTY_MIN`, `HAPTIC_DOMINANCE_NUM/DEN`.

## Queued (in order)

1. **Walk-test the directional haptics + tune.** The drive is implemented and bench-confirmed; now wear it and walk.
   - Tune `HAPTIC_DUTY_MIN` (currently 130) — raise if the motor still feels weak right at the alert threshold, lower if it's too strong across the whole band.
   - Confirm direction holds while moving (left obstacle → left temple, etc.) and that two-sided/doorway scenes fire both side motors with dominance contrast.
   - **Open watch item:** HTTP server wedged once when motors ran sustained at high duty point-blank (~11 cm desk obstacle). Did not recur in normal use. If it reproduces during walking: add motor-terminal 100 nF + rail 100 µF caps (mailed), a duty cap, or an HTTP watchdog.
2. **Solder perfboard for the helmet rim** when 1N5819 Schottky kit arrives — three 2N3904s, three 1 kΩ resistors, three flyback diodes (cathode → 3V3), one 100 µF bulk cap across 3V3, JST connectors out to motors.
3. **Multi-target per zone** (`VL53L8CX_NB_TARGET_PER_ZONE = 2`) — helps thin obstacles in open doorways. ~40 line firmware change.
4. **Dynamic wearable testing.** Walk hallways, doorways, around furniture. Specifically test: pullup bar / overhead doorframe, chair near body, dark fabric, glass at angle, lighting changes (indoor → outdoor). Decide whether 2nd sensor is needed.
5. **Second VL53L8CX aimed downward** (SPI bus) for the belly-button-and-below blind spot.

## Research synthesis (2026-05-26)

Did a full Phase-1 data re-analysis (latency-focused wearable lens) + spawned 3 background research agents (ST docs, academic literature, market survey). All findings written up in [`docs/research-optimal-config.md`](docs/research-optimal-config.md).

Key conclusions baked into firmware:
- **4×4 @ 30 Hz currently** (Phase 1 latency analysis showed frame latency dominates per-zone noise by 10–40× for a moving user; 60 Hz worth testing)
- CONTINUOUS mode, sharpener 5, TARGET_ORDER CLOSEST (defensible at our <100 ms budget per ST)
- Per-row thresholds 60/60/80/95 cm (4×4) — our innovation, not in literature
- Ratio-based beep urgency (forward / row_threshold) with squared curve — our innovation
- 3-motor directional haptic ring (LEFT/CENTER/RIGHT temple/forehead) — wired + verified + research-backed, column-mapping logic pending (see Queued #1)

What's empirically open (publishable contributions):
- No published paper has tested VL53L8CX on a head-mounted ETA for visually impaired
- No paper has measured detection latency vs frame rate for moving pedestrian
- No paper has characterised ground-plane false-positives for downward-pitched head mount
- No published outdoor / direct-sun VL53L8CX wearable data

## Live test snapshots

- **2026-05-25:** Bumped `MOUNT_PITCH_DEG` 13° → 20° based on user re-measurement after physical mount adjustment. Should be re-verified with another wall-stare capture when convenient. Compensation table at 20° pitch on 8x8: row 0 cos = 0.98 (top, basically unchanged), row 7 cos = 0.74 (bottom, ~26% reduction).
- **2026-05-25:** ESP-direct web viewer live at `http://192.168.1.228/`. Phone-friendly. Shows nearest forward distance + 8×8 grid with red=close, green=far. Polls `/api/status` every 200 ms.

## Dynamic-testing findings (live observations during wearable testing)

- **2026-05-25: chest-and-below obstacles invisible at close range.** Confirmed by walking-around test. Sensor at 186 cm helmet height + 13° pitch + 22.5° half-FoV means bottom edge of view is 35.5° below horizontal. Belly button (~120 cm body) at 60 cm forward needs 47.7° down → outside cone. Chest (~140 cm) needs 37.5° down → also outside. Slant compensation can't fix this — it's the FoV geometry. **Vertical angular range needed to cover "slightly-above-head + belly-button at 60 cm" = ~61°, but sensor only has 45° vertical FoV. One head-mounted sensor cannot cover both ends.** Options:
  - Bump `MOUNT_PITCH_DEG` to **20°** (recommended single-sensor compromise): top of FoV at 2.5° above horizontal (keeps a bit of head-height coverage), bottom at 42.5° (catches down to lower chest at 60 cm). Belly button still uncovered.
  - Bump to 25–30° to catch belly button, lose all above-horizontal coverage.
  - Mount sensor lower on body (chest). Belly button becomes near-horizontal. Loses overhead.
  - Add second VL53L8CX aimed downward (already on future-ideas list — this is the real fix).

## Future ideas (no commitment, log only)

- [ ] **iPhone as IMU stand-in** (until real IMU breakout arrives). Stream IMU over WiFi UDP via SensorLog/Phyphox. Trade-offs: bulk, battery, latency. Reuben asked about hardwired UART — see "Hardware notes" below.
- [ ] **Adaptive geometric calibration once IMU is installed.** Use live pitch reading to update each zone's elevation angle in real time instead of assuming level head. Eliminates the fixed-mount-angle approximation.
- [ ] **Layered alert thresholds.** 120 cm = slow chirp, 60 cm = fast chirp, 30 cm = solid tone. Much higher information density for a blind user than binary on/off.
- [ ] **Min-zone-count for alert trigger.** Require ≥2 adjacent zones below threshold to reduce single-pixel false alerts (e.g. a thin reflective speck).
- [ ] **Second VL53L8CX sensor.** Adds peripheral coverage / floor detection. Risks: VCSEL-to-VCSEL optical interference (mitigate with non-overlapping aim OR external-sync pin), I²C address conflict (use SPI bus instead — cleaner with multiple sensors, no address conflict, ~10 MHz vs 400 kHz). Defer until single-sensor dynamic testing reveals where coverage gaps actually matter.
- [ ] **CV-adaptive thresholds (Phase 2).** Different beep pattern for person vs wall vs static obstacle once camera + CV is integrated.

## Hardware notes / open questions

- **iPhone over Lightning/USB-C → ESP32 UART (hardwired).** Not practical without an Apple MFi-licensed authentication chip on the ESP side. iPhones require MFi handshake for arbitrary serial I/O over Lightning. USB-C iPhones (15+) are slightly more open but still mostly locked down for serial. Realistic path is WiFi UDP, not UART.
- **iPhone ↔ PC photo transfer works without MFi** because it uses USB PTP/MTP (Picture Transfer Protocol / Media Transfer Protocol), which are USB standard device classes — any computer's USB stack supports them natively. MFi is only required for Apple's proprietary iAP/iAP2 protocol used by audio accessories and custom Made-for-iPhone hardware that wants arbitrary serial I/O. So the MFi chip is on the *accessory* side (e.g. a CarPlay head unit), not the computer.

## Verified from ST UM3109 (downloaded 2026-05-25)

### §4.9 Target order
- "The VL53L8CX can measure several targets per zone. Thanks to the histogram processing, the host is able to choose the order of reported targets."
- Two options: **CLOSEST** (closest first) or **STRONGEST** (strongest first).
- **Default = STRONGEST.** Our firmware explicitly overrides to CLOSEST for obstacle avoidance — without that override the sensor would report the wall instead of a closer thin object.
- Target order works at NB=1 (selects which single target gets reported) AND at NB>1 (orders the list).

### §4.10 Multiple targets per zone
- VL53L8CX can report up to 4 targets per zone.
- **Minimum distance between two targets to be DETECTED as separate = 600 mm.** Two objects closer than 60 cm apart get merged into one weighted peak regardless of NB_TARGET_PER_ZONE.
- Configured via `VL53L8CX_NB_TARGET_PER_ZONE` macro in `platform.h`, value 1–4.
- Default = 1 (one target per zone).
- Higher NB → more RAM per frame on the ESP side.

### Implication for the pullup-bar problem
- Bar in doorway with **open space behind it** (gap > 60 cm) → NB=2 + CLOSEST will resolve the bar separately. Worth trying.
- Bar with **wall close behind it** (gap < 60 cm) → multi-target won't help, sensor fundamentally can't separate them. Need a different approach (different mount angle, second sensor aimed slightly upward, etc.).

## OTA root-cause finding — RESOLVED 2026-05-26

Spent the evening of 2026-05-25 debugging "OTA fails mid-stream" with serial captures over COM10. Real cause:

- **Verbose logging was throttling OTA to UART speed.** With `CONFIG_LOG_DEFAULT_LEVEL_VERBOSE`, every OTA chunk produced ~400 B of UART log output. At 115200 baud (~11 KB/s ceiling), log writes blocked the OTA task, slowing the whole transfer to ~15 KB/s. A 930 KB OTA then took 60+ seconds and curl's `--max-time 90` clipped the tail.
- **Heap was healthy throughout** (237 KB free, min-free 229 KB stable). Disproves the heap-fragmentation hypothesis.
- **`esp_ota_write` succeeded on every chunk.** No actual partition corruption this session. Earlier 65 KB mid-stream drops were real partition damage from accumulated bad-OTA boots before rollback was enabled — those are prevented now.

**Fix applied:** `sdkconfig.defaults` reverted to `CONFIG_LOG_DEFAULT_LEVEL_INFO`. OTA-handler heap-progress logs kept (INFO level, no throttle penalty).

**Verified 2026-05-26 morning:** OTA push timed at **6.3 seconds at 164 KB/s** (was 60+ s at 15 KB/s). Clean reboot, sensor streaming after, heap healthy. Case closed.

**What still could break OTA (recoverable, not blocking):**
- Sensor I²C init flake (~20% of warm reboots) — **LIKELY ROOT-CAUSED 2026-06-08:** `FREERTOS_HZ=100` made the IMU task's 2 ms delay round to 0 → it spun and starved the ToF loop at the shared mutex. Fixed by `FREERTOS_HZ=1000`. Watch whether the flake recurs after this.
- Other future causes (long-uptime heap fragmentation, WiFi rate-limit) → all diagnostic plumbing in place: `serial_capture.py`, `/api/health`, per-chunk heap logs, runtime `esp_log_level_set("OTA", ESP_LOG_VERBOSE)` to enable verbose without throttling.

## Recurring bugs / pitfalls (don't repeat)

- ESP I²C sensor init fails ~20% of the time on warm reboot. Mitigation: host-side 3× retry in `run_one_test.ps1`. **2026-06-08: likely root-caused as the `FREERTOS_HZ=100` IMU-task spin starving the ToF loop — fixed by `FREERTOS_HZ=1000`; verify the flake is gone.** Also: USB-Serial-JTAG re-enumerates on an RTS reset, so don't RTS-reset to start a capture — attach to the running stream or reset via `esptool`.
- ~~OTA can leave one partition in a corrupted state after many cycles.~~ **FIXED** with `CONFIG_BOOTLOADER_APP_ROLLBACK_ENABLE=y` + `esp_ota_mark_app_valid_cancel_rollback()` call in `ota_rollback_confirm_task` (waits for WiFi + first sensor frame, then confirms). Bad OTAs now auto-revert to the previous slot instead of bricking.
- PowerShell em-dashes (`—`) in `.ps1` files trip Windows PS 5.1 parser. Stick to ASCII.
- Reader-thread Qt signal queue accumulation makes the visualizer lag after thousands of frames. Fixed: GUI polls latest frame at 30 Hz via QTimer, drops intermediate.

## Done

- [x] Stream `range_sigma_mm` from firmware (v8)
- [x] Build measurement script with per-zone stdev (v8)
- [x] WiFi streaming (v7)
- [x] OTA reflashing via WiFi (v7)
- [x] Buzzer obstacle alert with distance-proportional beep rate (v8)
- [x] Module 5 sensor tuning section (course side, separate)
- [x] 17-config × 3-distance black foam sweep with retry logic (v9)
- [x] Data analysis pipeline (`analyze.py` → 8 plots) (v9)
- [x] Multi-client TCP fan-out (visualizer + measure.py simultaneously) (v9)
- [x] `STATUS:` line streaming for raw per-zone status codes (v9)
- [x] Compile-time `MOUNT_ROTATION_DEG` firmware-side rotation
- [x] Visualizer frame-rate decoupling (fixes lag accumulation)

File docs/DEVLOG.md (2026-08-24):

# Assistive Helmet — Engineering Devlog

A running log of the build: problems, root causes, fixes, and lessons. Newest first.

---

## 2026-08-24 (afternoon) — Zenbook field deploy, directive nag fix, fleet launcher

**Zenbook deployment**: Iris ran end-to-end on Reubens-Laptop (helmet
camera moved over; frames + callouts live). Blockers found and fixed:
Windows Firewall (added port-8123 rule), home WiFi profile was Public →
set Private, and the helmet camera was still plugged into the Legion —
PnP enumeration proved it; "no usable camera" was never a code bug.
**Bench shootout** (`camera/bench_machine.py` → docs/BENCH-MACHINES.md):
Zenbook 104 ms YOLO median vs Legion 170 ms — Tiger Lake AVX-512 beats
the older i7; torch is CPU-only on BOTH (the GTX 1650 has never run
YOLO). Verdict: Zenbook is fast enough — the safety loop has no NN in it.

**Voice fix**: voice_log showed `"iris [unk]" → rejected-unk` — the mic
heard the wake word but ambient noise glued into the same utterance and
the strict [unk] filter binned it. Now [unk] tokens are stripped before
matching; the wake word arms even with noise around it; ungated words
("stop") stay strict. Lesson: one read of the log answered what guessing
never would have.

**Wrong-name fix**: nano-seg mislabels on fisheye+blur were being spoken.
Naming ladder (`_det_name`): conf ≥ 0.70 → name, ≥ 0.55 → "maybe X",
below → just "obstacle". A wrong name is worse than no name.

**Directive nag fix** (user: "it kept yelling step left… say it once or
twice per obstacle — the person can assume it's still there"): directives
warn twice per encounter, then go silent. IMU stillness detector
(pitch+yaw rate < 6 °/s for 1.5 s) silences repeats while standing
still; closing another 0.4 m re-arms the pair; hazard absent 4 s = new
encounter. No IMU → treated as moving (never silence blind). Ticker +
haptics never stop carrying the range.

**Fleet launcher**: one home-screen icon finds whichever machine runs
Iris — each launcher proxies to its peer's live cv_fusion when its own
is down; the Start page offers "Start on Legion / Start on Zenbook".
Also: orbit-arc start page, in-app help overlay (? button),
docs/USER-GUIDE.md, phone rotate button (fills a portrait screen with
the landscape frame; works under iOS rotation lock).

**Ops lessons**: Task Scheduler `/it` one-shots can wedge at "Queued";
Windows OpenSSH kills child processes at session end — the only reliable
interactive start is the user's own double-click or the Startup folder at
login. Repo history was intentionally rewritten upstream (snapshot
purge); consumer clones re-sync with `git checkout -B main origin/main`.

---

## 2026-08-24 — Iris phone app (PWA) + always-on launcher; OTA flashed; audio mystery closed

**OTA + verification (morning)**: helmet came up at **192.168.1.227**
(DHCP moved it from .228 — defaults updated across all tools). Flash
succeeded (926 KB / 5.3 s); `/api/pattern?p=duck` fired the motors;
serial at rest showed ONLY Q: lines (zero false TAP:/DROP:) — correct
baseline. Full health sweep passed: all modules compile, beacon assets,
Vosk grammars, NIM key + live OCR (1.2 s), all calibration artifacts.

**Wake word renamed → "Iris"** (user's pick: iris of the eye + goddess
of sight). "Iris, describe" etc.

**Phone app built — the PWA path** (no Apple dev account): manifest +
apple-mobile-web-app meta → Safari Add to Home Screen → fullscreen app
with its own generated iris icon. Iterations driven by live user
testing, each with a root-cause lesson:
- *"Buttons do nothing"* → they worked (flightlog proved describe fired
  3×, VLM answered) — the camera sat 32 cm from a wall so the
  **"stop stop" directive monopolized the single speech slot**.
  Behavior correct; UX lesson recorded.
- *"No audio"* → desktop default output/volume fine; user later
  confirmed audio working on the computer. En route: found ports
  8090-8093 squatted by the known workspace-mcp leak (a stray Python
  3.14 server answering 404 to everything) → **dashboard moved to
  :8123**.
- *"Video doesn't auto-start"* → two real causes, both fixed:
  (1) long-lived MJPEG `<img>` streams silently stall in iOS standalone
  PWAs → replaced with **single-frame polling** (fetch+blob ~8 fps,
  self-healing); (2) iOS caches the PWA's start HTML indefinitely →
  **Cache-Control: no-store** on everything.
- UI iterations: big buttons → compact icon sidebar → emojis → inline
  SVG line icons → **translucent blur overlays with letterbox-aware JS
  placement** (video always max-size uncropped; buttons live in the
  black bars, overlay a corner only when no dead space exists).
- **Desktop parity**: the OpenCV window now draws the same four
  buttons (radar/eye/speaker/flag) as clickable translucent overlays —
  one dispatch queue serves voice, phone, desktop clicks, and keys.
- **Starts MUTED by default** now (`--audio-on` to override) — no more
  stop-stop spam on every launch.

**Always-on launcher** (`camera/launcher.py`): owns :8123 permanently;
proxies to cv_fusion (now on internal :8125) when running; otherwise
serves a Start page whose button spawns cv_fusion and auto-reloads into
the dashboard. Startup-folder entry installed
(`iris_launcher.bat`) so the phone icon answers after any reboot.
End-to-end verified: start page → /launch → spawn → proxied status +
121 KB frames.

**Lesson**: every "the button is broken" report today was the system
working correctly with an invisible reason (directive monopoly, stale
PWA cache, dead stream object). Instrumentation (flightlog, vlm_log)
turned each vague report into a 2-minute diagnosis — the measurement
layer paid for itself on day one.

---

## 2026-08-23 (earlier same day) — VLM, voice control, OCR benchmark, planning apparatus

Before the evening sprint below, the day built the query stack and the
plan that made the sprint possible:

- **VLM "describe" shipped** (keys v/h): benchmarked local Qwen3-VL-2B
  on the desktop GTX 1650 — **20–25 s/answer, FAIL** (first benchmark's
  "3.8 s" was an empty truncated-thinking answer; lesson: check the
  ANSWER, not the clock). NVIDIA NIM cloud llama-3.2-11b-vision (user's
  free key) = **2.3–6.4 s with correct abstention** ("too blurry — can't
  identify") → NIM is the path on both machines (field laptop = Iris Xe,
  no CUDA). `camera/vlm.py` built to the industry checklist
  (docs/VLM-BUILD-SPEC.md): env-var secrets, timeouts+retry,
  single-flight, honest spoken failures, blur-aware frame pick,
  sensor-context grounding, forced abstention, jsonl logging.
- **nemotron-ocr-v2 benchmarked**: 1.3–2.4 s, per-word boxes; read a
  synthetic "HEINZ / TOMATO KETCHUP" label at 0.92 conf and found every
  probe word on a text-dense screenshot → became the find-by-text
  engine.
- **Voice control shipped** (`camera/voice.py`): research first
  (voice-commands-2026-08-23.md) CORRECTED the naive design — Vosk
  grammar mode force-matches bystander speech (vosk-api #1339), so
  always-on ungated is out; shipped the industry shape instead: wake
  word "helmet" arms a 5 s window; "stop"/"quiet"/"wrong" ungated;
  half-duplex (mic dropped while our TTS speaks); every utterance
  logged.
- **Field laptop verified for the whole stack over SSH**: repo pulled,
  vosk+model+sounddevice installed, NIM key placed, YOLO-World
  benchmarked at **114 ms/frame (2× faster than the desktop)**; mic
  array present. VLM stays cloud (no NVIDIA GPU).
- **4-agent research-gap assessment** over the entire corpus →
  FEATURE-GAP-VERDICT-2026-08-23.md (5 convergent adds, ruthless cuts:
  on-track ping, pulse vocab >2, text earcon, seat auto-pick, vehicle
  interlock, trajectory prediction — each contradicted by its own
  evidence).
- **Planning apparatus**: 4 scoping agents wrote 10 implementation
  plans (docs/plans/PLAN-*.md, ~1,800 lines, real line anchors from the
  code) + GRAND-PLAN.md with dependency ordering and an Aug-29 deadline
  guard. This is what made the evening sprint mechanical.

---

## 2026-08-23 — GRAND PLAN executed: 9 features in one sprint

All build items of docs/plans/GRAND-PLAN.md landed in a single evening
(each from its own scoped PLAN-*.md; every item compiled + unit/live
tested where testable without the wearer):

1. **Flight logging** (`flightlog.py` + `session_report.py`): every
   spoken alert logged; implicit FP votes (hush within 10 s of a
   caution) + explicit ("wrong"/key x); 60 s RAM ring (2 fps 360p JPEG +
   ToF grids + 20 Hz IMU) persisted ONLY on triggers (override, manual
   "flag that", ToF/CV disagreement, directive) — the openpilot pattern
   at fleet-size 1. Verified end-to-end: events, votes, 3 clips, npz,
   report math.
2. **Steps-not-meters**: dead `spoken_range()` resurrected as
   `spoken_steps()`; `--calibrate-stride` CLI; `--units auto` (walking =
   steps, query = meters) + key `u`. Unit-tested.
3. **Head-turn speech gate**: yaw-rate estimator on the Q: stream
   (120 ms endpoint delta + EMA — verified: tracks 191°/s synthetic,
   decays on stop); gates CAUTION only at 100/60°/s hysteresis + 250 ms
   dwell; directive/query/ticker never gated; events logged (the
   citable novelty claim).
4. **Firmware batch** (built, OTA PENDING — helmet was offline):
   SH2_TAP_DETECTOR → `TAP:1/2` lines (double-tap → VLM describe,
   1 s debounce); accelerometer 50 Hz freefall→impact drop detector →
   `DROP:1/0` (laptop announces "helmet dropped" every 10 s, hazard
   speech muted while down); `/api/pattern?p=duck` (all-motor double
   pulse); `/api/tunnel?l&r&ttl` (TTL-guarded corridor duties
   max-blended in haptic_apply).
5. **Around-Me interrogation layers**: ONE responder for F9 / voice /
   future tap; front-left/center/right sectors + honest "behind you I
   can't see"; repeat ≤10 s peels labels → ranges → VLM one-liner.
6. **Find-by-text flagship** (`ocr.py`, nemotron-ocr-v2): voice "find
   exit" (curated grammar) or key f (any word) → OCR while panning →
   fuzzy match (Levenshtein ≤1, conf ≥0.6, len ≥3) → world-bearing
   beacon lock (yaw sampled AT FRAME GRAB — the #1 flagged bug) →
   re-OCR every 2 s → arrival by ToF range. Live-tested: found "EXIT"
   at 0.92 conf on a synthetic frame. "Read that" (key r / voice)
   speaks the dominant text line.
7. **Gravity-frame head-clearance watch (flagship)**: per-zone world
   height via cam→helmet (R_CH, geometry-verified: level = −765 mm at
   2 m on boresight; pitched up 22.5° = 0) → live IMU attitude;
   ±margin band in the path cone; 3-of-5 persistence; caution at 2 m,
   "low clearance, duck" directive + firmware duck pattern at 1.2 m.
   Feature OFF (spoken once) without IMU+mount-cal — never a
   sensor-frame fallback. KNOWN LIMIT (documented in the plan): top
   zone edge sits ~+1° above horizontal, so overhead coverage leans on
   the ±8° gait pitch sweep; splay re-aim is the v2 fix if field tests
   demand it.
8. **Spatialized ticker**: ticks now pan to the hazard's azimuth
   (ClickPlayer, constant-power ILD ×1.5 exaggeration per the BC
   research), TTC law unchanged; mono winsound fallback. Audible smoke
   test passed (left/center/right sweep + trill).
9. **Walkable tunnel** (key `n`, TCP mode): lateral wall distance from
   upper zones → duty ramp 90–200 inside 1.2 m → `/api/tunnel` at 4 Hz;
   silence when centered (.lumen's unclaimed mechanism).

**Also today**: laptop verified field-ready for the whole stack
(door-scan 114 ms/frame — 2× faster than the desktop; vosk + models +
NIM key installed; mic array present).

**Lesson**: scoped plan docs with real line anchors made a 9-feature
sprint mechanical — every edit script asserted its anchors before
touching the file, so drift failed loudly instead of corrupting.

**OTA FLASHED 2026-08-23 22:30** — helmet found at 192.168.1.227 (DHCP
had moved it from .228). Flash succeeded (926 KB, 5.3 s). Verified live:
`/api/pattern?p=duck` returned 200 and fired the motors; serial stream
at rest shows ONLY Q: lines (98 samples, zero false TAP:/DROP:) —
correct baseline, no false triggers sitting still.

**Pending**: live walk test of everything (item 0 — tap-through-foam,
drop truth-table, find/door/VLM/voice, duck-under-broom), demo video
(item 10).

---

## 2026-08-22 — Scan-and-select door guidance (key `d` → 1/2/3) + VLM path decided

**Door guidance built** per the last-meter research spec
(research-sources/last-meter-doors-2026-08-22.md):

- **Problem**: COCO has no door class — our main detector can't see
  doors at all. **Fix**: YOLO-World (open-vocabulary) loaded lazily in a
  background thread, prompted with ["door", "glass door", "doorway",
  "double door"], run ON DEMAND only (0.2 s/frame at 640 — verified on
  real helmet snapshots; found the door in cvfusion_headless_test.png
  at 0.21 conf).
- **Flow**: `d` → "scanning for doors, pan slowly" (3.5 s, ~15 frames)
  → detections anchored in WORLD bearing (pixel azimuth + IMU yaw at
  grab), clustered at 14°, ≤3 candidates spoken with clock bearing +
  bbox-height range estimate (2.03 m standard leaf) → user presses
  1/2/3 → Soundscape beacon locks the world bearing (survives leaving
  frame; 1.2 s re-detect loop re-fixes bearing/range) → arrival <1.2 m
  facing → outro + "door reached." **Never guides anywhere the user
  didn't pick** — the scan-and-select ruling.
- Door mode and object-guide (`g`) yield to each other; F8/leveling
  mute respected; no-IMU degrades to redetect-only tracking.
- Verified: py_compile clean, bearing-wrap/clock/ranging unit math,
  real-frame detection smoke test. **Awaiting live walk test.**

**VLM decision same day**: local Qwen3-VL-2B on the desktop GTX 1650 =
20–25 s/answer (FAIL — and the first benchmark's "3.8 s" was an empty
truncated-thinking answer; lesson: always check the ANSWER, not just
the clock). NVIDIA NIM cloud llama-3.2-11b-vision (user's free key) =
2.3–6.4 s with correct abstention on unanswerables → NIM is the VLM
path on this machine; re-benchmark locally on the field laptop.

---

## 2026-08-21 — IMU mount calibration DONE (voice-guided) — the long-standing blocker cleared

**Problem**: `imu_mount_cal.py` had sat un-run for days because it needs
the user's hands AND the stock script needs keyboard Enters at a terminal
the user isn't watching while holding a helmet.

**False alarm en route**: first attempts returned 0° between poses with
near-zero noise, and a motion test showed a frozen gravity vector —
diagnosed as "BNO085 stuck, power-cycle it." **Root cause was actually
that the user had never moved the helmet** — the beep choreography wasn't
reaching him (terminal prints + beeps with no explanation he could follow
while away from the screen). Lesson: a hands-busy calibration must carry
its own instructions IN AUDIO; and "sensor stuck" needs the user
confirmed in-the-loop before you believe it.

**Fix that worked**: rewrote the flow as a VOICE-GUIDED script (pyttsx3
speaks each step) + stillness-gated sampling (4 s windows retried until
angular spread ≤3°) — no timing pressure, no terminal-watching. Same
math as the stock script (two-pose gravity + cardinal snap).

**Result**: pose angle 71.6° (usable band 60–120), hold error 5.1°
(absorbed by snap). Mount = chip X/Y swapped, Z inverted — clean
cardinal. Verified live: nod → pitch only, right-ear-down → roll +,
left turn → yaw +. Saved `visualizer/imu_mount_cal.json`.

**Unlocks**: correct HUD attitude labels, voice leveling coach accuracy,
gravity-frame head-clearance, pose-aware floor rejection, beacon
lost-target tracking sign verification.

---

## 2026-08-20 — Soundscape audio beacon ported into cv_fusion (key `g`)

**Feature**: lock any detected object and Microsoft Soundscape's actual
4-region audio beacon leads you to it — the original MIT-licensed WAVs
(`camera/assets/soundscape_beacon/`), played by a faithful port of their
engine (`camera/beacon.py`, ~170 lines, sounddevice).

- **How it behaves**: timbre encodes how far off-axis your head is (A+
  ±10° "on it" / A ±55° / B ±125° / Behind), stereo pan encodes the side,
  region changes land on the next *beat boundary* (6 beats/phrase — the
  Soundscape trick that makes head-scanning sound musical, read from
  their `DynamicAudioPlayer.swift`). Distance stays out of the beacon
  (their choice too); arrival (<1 m) plays the Route_End outro + speaks
  "arrived". Target loss → beacon **dims, never stops** (their
  no-heading rule), with IMU yaw-delta keeping a bearing estimate; 8 s
  lost → "guide lost".
- **UX**: `g` locks the nearest ranged detection ("guiding to chair"),
  `g` again cancels; magenta box + GUIDING HUD; mutes with F8/leveling
  and re-arms after.
- **Verified**: py_compile clean; offline unit tests (region thresholds
  vs Soundscape's verbatim selector, constant-power pan direction,
  beat-boundary switching, outro path) all pass; live audio smoke test
  played the full sweep + arrival melody through the default output.
- **To verify on hardware**: the lost-target IMU sign convention (marked
  in code — if the beacon runs *away* from an off-screen target, flip
  one sign) and beacon-vs-ticker loudness balance on the real speakers.
- **Lesson**: reading the original implementation beat re-inventing it —
  the beat-quantized region swap would never have occurred to us, and
  it's the single detail that makes the beacon pleasant instead of
  glitchy.

---

## 2026-08-17 (evening) — Full hardware complete: motors + switch wired, ID'd, mounted

**Every subsystem is now wired and verified.** The helmet hardware is done.

### Motors (3× ERM coin, 2N3904 low-side, 1 kΩ base, no flyback — user's call)
- Wired to "the next 3 header pins after the ToFs" = **GPIO 17, 18, 8**.
- **Bug: GPIO 17 buzzed non-stop** — the old pause-switch code still configured
  17 as input+pullup, fighting the motor output. Switch code compiled out →
  fixed. Lesson: a reassigned pin's OLD role lives on until you grep for it.
- Then "two motors buzzing like crazy" = NOT a bug — the directional haptics
  were live and the desk was inside alert range. The system worked before we
  believed it.
- **Overheating scare handled remotely**: exploited the new `/api/motor`
  manual-hold to spam zero-duty pulses as an improvised kill switch while the
  real mute endpoint was built and flashed.
- **New firmware endpoints** (no more reflash-per-test):
  `GET /api/motor?i=0..2&duty=0..255&ms=20..2000` (manual pulse, overrides the
  ranging drive during the pulse) and `GET /api/haptics?en=0|1` (software mute).
- **Mounted-position ID (pulse test, user feedback): GPIO 17 = LEFT temple,
  18 = CENTER forehead, 8 = RIGHT temple.** Firmware's guess was wrong on all
  three; defines corrected and **OTA-flashed over WiFi** (USB kept dropping —
  OTA saved the session twice).

### Pause switch
- SPDT toggle: COM → **GPIO 3** (strapping pin, safe — JTAG role needs an
  unburned eFuse), outer → GND, internal pullup. Verified live: 4 clean
  transitions in `/api/status.haptics` while flipping.
- With the switch enabled it overrides the web toggle every frame.

### Pre-glue diagnostic (all PASS)
- Boot: A + B + IMU + WiFi + switch all up. Streams: both ToF at 28 Hz, IMU
  quats at 28 Hz (emitted per ranging frame), quaternion norm 1.0000, cal
  status 3/3, sample noise 0.5°. Zone-health snapshot was meaningless (sensors
  were lying against the desk reading 5–23 mm) — rerun facing open space
  before trusting field quality. Drift number (4.5°/min) also needs an
  untouched retest.

### Haptic contact issue (open)
Motor contact area on the forehead too small. Plan: rigid puck per motor to
spread vibration + foam preload behind it; couple to skin, DECOUPLE from
shell (shell radiates audible buzz next to the ears — masking risk).

### Open next session
1. Confirm the corrected motor order end-to-end (should pulse centre→right→left
   as channels 0→1→2 post-OTA; user hadn't confirmed before shutdown).
2. Re-run zone-health + IMU drift diagnostics with the pod facing open space.
3. `imu_mount_cal.py` — STILL not run; gates all IMU features.
4. Motor puck/foam mounting; v11 column→motor mapping redesign for the
   left/right sensor pair.
5. Dewarp A/B verdict (wardrobe-TV test) still unreported.

---

## 2026-08-17 — Helmet firmware flashed, IMU live, unified viewer, voice-guided leveling

### Firmware flashed + full stack verified
Flashed last night's rebuild (final ToF pins, perpendicular-distance fix) to
COM9. Boot log: sensor A ranging, sensor B online, WiFi up (192.168.1.228, TCP
3333 + HTTP viewer). **User wired the IMU onto sensor A's bus (6/7)** per
`docs/WIRING.md` — BNO085 online at 0x4A, handshake in 130 ms. The early
"no device at 0x4A" probe warning is cosmetic (fires before the IMU boots).
Only the 3 haptic motors remain unwired. **Hardware buzzer CANCELLED** (user
decision): the compute device's digital sounds replace it.

### Unified viewer: cv_fusion now speaks helmet-firmware
- New `--source helmet` (default): TCP reader for `DATA:`/`DATAT:`/`Q:` lines —
  ToF grids + IMU quaternion over WiFi, no COM-port contention. Firmware sends
  invalid zones as 4000, remapped to the ">0 = valid" convention.
- **Camera-index trap, twice in one morning**: USB re-enumeration moved the
  helmet cam 1→0; a brightness-based auto-pick then chose the LAPTOP webcam
  because the pod was lying lens-down. Fix: select by DirectShow device NAME
  ("HBV HD CAMERA") via pygrabber. Names, not indices, not brightness.
- **3D attitude inset** (top-right): cv2-wireframe of the pod (plate, cyan/
  yellow ±22.5° sensor panels, camera stub, up-post) rotating live with the
  IMU, plus a yaw compass ring. Artificial horizon on the main view once the
  mount cal exists.
- **winsound.Beep is full-volume with no gain control** — it drowned the
  speech (user: "can't hear what the commands are"). Replaced ticker + cue
  with generated low-amplitude WAVs (0.10 / 0.22 FS) via PlaySound, and the
  ticker now MUTES during utterances.

### IMU mount calibration + ball-mount leveling
- `visualizer/imu_mount_cal.py`: two-pose gravity alignment (level, nose-down)
  → R_chip_to_helmet. User's insight simplified it: the IMU board is mounted
  FLAT and SQUARE on the pod base, so the result is **snapped to the nearest
  of the 24 cardinal orientations**; the snap deviation doubles as a
  mounting-error measurement. NOT YET RUN — needs his hands.
- The pod hangs on a **ball camera mount** (new info) — attitude vs the helmet
  drifts on every re-clamp, which makes the IMU the alignment instrument:
  - `visualizer/mount_level.py`: standalone bubble level (bench use).
  - **cv_fusion key `l` = voice-guided leveling mode**: "tilt up 5" → "tilt
    left 2" → "level, lock it", auto-exits when confirmed. Hazard voice +
    ticker pause during it. The blind-user version of a spirit level.

### Open before next session
1. **Run `imu_mount_cal.py`** (2 min, user's hands) — everything IMU-labelled
   waits on it: horizon, attitude model truth, leveling-mode directions.
2. Wire 3 motors (user supplies pins) → firmware pin update + ID pulse test →
   temple-haptics direction channel (the [HW] track in MASTER-SYNTHESIS).
3. Walk-test the v2 voice + M3 demo captures.
4. IMU next uses: sterile-cockpit gate (suppress speech during fast head
   turns), ToF↔camera de-rotation, ground-plane bbox ranging.

---

## 2026-08-16 (night, autonomous run 2) — Callout engine v2: research says we were 30× too chatty

Third research stream landed (`research-sources/blv-usefulness-2026-08-16.md`)
and overturned parts of the evening's design. Everything merged into
`docs/MASTER-SYNTHESIS-2026-08-16.md`; all [BUILD NOW] items implemented and
smoke-tested against live hardware in one unattended pass.

### What the evidence overturned
- **2 s narration cadence** → Soundscape (open source — actual constants read
  from `AutoCalloutGenerator.swift`) never repeats an object within **60 s**
  and treats **silence as the default state**. Chatter is the #1 named
  abandonment cause in users' own words.
- **Numbers in walking speech** → no shipped product does it. Proximity is a
  **repetition rate** (parking-sensor pattern; Apple/Oko/biped all encode it
  non-verbally). Also van Erp 2020: 2-item recall ceiling while walking —
  "person left, 2" was already one item over.
- **Person callouts** → the *least*-wanted feature in BLV user studies ("the
  dog detects those people"). Head-height obstacles are the product: 13% of
  ~300 blind people suffer head-level accidents monthly, cane or dog
  regardless.

### Built (cv_fusion.py v2 + callout_trainer.py)
- **Silence-default engine**: routine tier deleted; speaks only hazards
  (<1.8 m or closing), directives, path-clear, sensors-lost. 60 s per-object
  cooldown, approach re-announces, stale queue items (>1.5 s) dropped unspoken.
- **Two-item grammar, no numbers**: "obstacle, left" / "maybe pole, ahead"
  ("maybe" = confidence hedging below 0.50, Soundscape's about/around pattern).
- **Proximity ticker**: sparse 600 Hz 40 ms blips, period 1.2 s→0.15 s over
  1.8 m→0.5 m, path-cone only. Distance now rides tempo, not words.
- **F9 scene query** (global hotkey): Apple two-tier verbosity — silence by
  default, detail on demand, numbers allowed there ("person ahead, about 2
  meters"), verbatim-Soundscape empty state: "There is nothing to call out
  right now."
- **Cane-blind-spot filter**: bottom ToF row (cane territory + mostly floor at
  the 22.5° mount) rendered but never spoken/ticked; hazards need rows 0–2.
- **Person deprioritized**: nearest hazard wins, no class priority.
- **ByteTrack**: worker switched `predict`→`track(persist=True)`; range history
  keyed by track ID so a second person can't inherit the first's history;
  closing (< −0.5 m/s) computed per-ID; distance still re-derived from the
  live ToF frame every cycle (red-team rule).
- **`--rate` flag** (blind listeners parse 8–22 syl/s; the ceiling is ours).
- **`camera/callout_trainer.py`**: flashcard drill for the brevity vocabulary,
  scores accuracy + reaction time — how pilots learn brevity, and the 60-second
  portfolio demo of the two-mode design.

### Verification
Compile-clean; ran 25 s+ against live camera + both ToF sensors without crash
(detector at ~10 fps seg + track, ticker and speech threads live). Left
running for the user's return. Untested pending a human: audible tick pacing,
F9 phrasing quality, directive feel while moving.

---

## 2026-08-16 (late evening, autonomous run) — Firmware fixed + CV fusion first light

User left the machine with "don't stop working until all is complete." Done in
sequence, everything verified as far as possible without hands:

### Firmware consolidated (built clean, NOT YET FLASHED — deliberate)
- ToF pins updated to the final wiring (A=6/7/4 bus0, B=15/16/5 bus1); bus
  ports swapped to match; sensor naming updated to A/left, B/right.
- **The cos-table double-correction is fixed**: `distance_mm` is perpendicular,
  so forward = z·cos(α+pitch)/**cos(α)** — the old slant factor applied a
  zone-elevation correction the value never contained, biasing outer rows ~8%.
- `MOUNT_PITCH` 30/−5 → 22.5/22.5 (group tilt), `MOUNT_ROTATION_DEG` 270 → 0
  (verify with viewer on first flash).
- Buzzer/motors parked on provisional free pins (40, 1/2/41) — NOT wired; user
  supplies real pins later. `idf.py build` passes, 1062/1062.
- **Not flashed because the CV work needs `tof_pin_test`'s GRID stream** on the
  ESP32 right now. Flash when switching back to helmet/haptics work.

### CV fusion built and hardware-verified (M1 + M2 of docs/CV-FUSION-PLAN.md)
- YOLO26n: **22 fps on laptop CPU at 416px**, live camera detection confirmed.
- `camera/cv_fusion.py`: detector in a worker thread, zone quads projected with
  the full joint calibration, box↔zone association in image space, box range =
  min over claimed zones, ToF-only near zones render as OBSTACLE alerts (CV
  can't name branches — ToF never misses them).
- **Headless end-to-end run against live hardware worked** — both sensors
  streaming, zones tiling with the designed centre seam visible on the room,
  detection + association + render verified
  (`camera/snapshots/cvfusion_headless_test*.png`).
- **Live data found a real bug immediately**: a person standing at the field
  edge overlapped zone quads but contained no zone centroid → no range.
  Fixed with a rect-overlap backup (>35% of zone area). Also caught, in one
  frame: the real person NOT detected while a clothes rack scored "person
  0.42" — the red-team's single-frame-detector warning, live. Tracking +
  temporal persistence is the planned answer, and alert logic must never
  gate a near ToF hit on CV agreement.

### Research pass (two Opus agents, reports archived verbatim)
`docs/research-sources/cv-stack-research-2026-08-16.md` — detector choice,
ToF+mono-depth fusion literature (CFPNet is nearly our hardware), what biped/
Sight Guide/the ETA RCT teach, value-for-effort ranking.
`docs/research-sources/cv-redteam-2026-08-16.md` — 21 ranked NOT-do-to items:
sunlight collapses ToF range to ~1 m; thin poles fall below the reflectance
floor; motor noise can erase the device's whole benefit (masking, +33%
contacts); cables ended Cybathlon runs, not algorithms; claims language fixed.
Decisions folded into `docs/CV-FUSION-PLAN.md` §Decisions.

---

## 2026-08-16 (evening) — The 8 mm residual diagnosed: signal-weighted zone centroids

> **Stage 4 first light, 21:30:** `camera/fusion_overlay.py` ran live against the pod
> (COM9 + camera 1) and the user confirmed it working. Both sensors' zone quads +
> surface-centroid dots rendered on the fisheye feed in real time.

Adversarial review of everything the earlier session left open. Ran the datasheet
(DS14161 Rev 12, now archived in `docs/datasheets/tof/` with extracted text), three
parallel research agents, and a residual autopsy on the captured pose data. Every
standing hypothesis was tested against data; one survived.

### The autopsy — five hypotheses, four executions
All run from the existing 17+22 poses, no new captures (`scratchpad/residual_autopsy.py`
logic now recorded here):

| hypothesis | test | verdict |
|---|---|---|
| tangent-uniform zone spacing | refit with tan-spaced rays | **worse** (8.58/9.29 vs 7.96/8.60) |
| per-zone distance bias | fit biases on even poses, score on odd | **fails CV** — held-out rms got worse |
| depth-scale mismatch (ToF or camera) | fit global z-scale / plane-d scale | rms barely moves (7.96→7.55 best) |
| fisheye periphery extrapolation | corner-coverage annulus + KB1–KB4 model-order sweep on the original 19 calib shots | **dead**: 39% of corners beyond 30° (max 61.8°), all four model orders agree within **0.08° at 45° off-axis**. Intrinsics contribute <0.1°, not 1.1° |
| effective (signal-weighted) zone centroids | free per-row/col ray table | **rms 7.96/8.60 → 4.22/4.80**, and A and B **independently agree on the table to ~1°** |

### The two signatures that identified it
1. **The error is per-POSE, not per-zone.** Per-zone mean residual is nearly flat
   (±2 mm) while total rms is 8 mm — so no static per-zone pattern exists. The
   variance lives *within* poses: ToF points fit their own plane at 3.1 mm but miss
   the camera's plane at ~7.4 mm. The planes disagree in **tilt**.
2. **Tilt disagreement correlates with board tilt** (+0.85 on sensor A). A lateral
   (angular) ray error is invisible on a frontal board — moving a point sideways on
   a frontal plane doesn't change its plane distance — and leaks into the residual
   in proportion to board tilt. Exactly what was observed.

### Root cause
**A zone's reported distance is a signal-weighted average over its cone, and the
signal is not uniform across the zone.** The VCSEL field of illumination is 43.4°
at 75% power and 57.9° at 10% (DS14161 §2.3) — outer zones are lit brightly on
their inner side and dimly on their outer side, so their *effective* centroid ray
is pulled inward. The 14% default sharpener (inter-zone bleed suppression) adds to
it. Fitted effective outer columns: ±13.4° where geometry says ±16.9°.

**Both prior measurements were right — they measure different things:**
- The tripod detection test measured the zone's geometric *bounds*: 45°, datasheet-true.
- The plane solver measured the zone's signal-weighted *centroid* on extended
  targets: ~34° effective span. Not a bug — a second, real property of the sensor.

Supporting fact from research: ST publishes per-zone ray tables
(`VL53L5_Zone_Pitch8x8`/`Zone_Yaw8x8`) — the real lens mapping is close to
tangent-uniform but off by up to ~1° per zone, i.e. ST themselves do not model the
field as uniform-in-angle. ST staff also confirm on the record that `distance_mm`
is **perpendicular, not radial** — closing that question permanently.

### The calibration that ships
Joint two-sensor solve with the CAD ToF-pair geometry enforced rigid (45.000°,
36.249 mm — known to sub-micron) and ONE shared effective ray table (same lens
design, two sensors): **rms 5.51 mm total** (A 5.59 / B 5.45, floors 3.08/3.27),
rotation 1.15° from CAD. Written to `camera/tof_calib_poses/solved_joint.json`.

**Usage rule for fusion:** geometric 45° bounds for *zone occupancy / frustum
drawing*; the effective centroid table for *extended-surface geometry*. A small
object in a zone can be anywhere in the geometric cone; a wall's reported distance
belongs to the effective centroid ray.

### Datasheet/research facts locked in (agent-verified, sources in the entry above)
- `distance_mm` is **perpendicular** — ST staff (John E KVAM) on the record, twice;
  the radial→perpendicular conversion happens on-chip. Closed permanently.
- 45° is **edge-to-edge** of the zone array; the 65° "diagonal" in DS14161 Table 2
  is an *empirical detection extent* (88% white target, 1 m, dark), geometrically
  inconsistent with 45×45 under any model — never derive zone angles from it.
- ST's own zone table is ≈ tangent-uniform but hand-tuned, ±1° accuracy, has a
  known bug (Yaw8x8 index 48: 203.20 should be 215.40), and no official 4×4 table
  exists. Sub-0.5° zone-geometry refinement is below the sensor's own spec.
- DS14161 §7.2.4: corner zones may degrade **up to 4%** vs the centre 4 (16 mm at
  400 mm). Cross-checked against our data: a per-zone *distance* bias would show on
  frontal boards, which it doesn't — so for our unit this term is small and the
  centroid explanation stands.
- Rx optical centre sits **1.720 mm** off package centre along the long axis
  (0.100 mm short axis), ray origin **0.736 mm** below the top face (Fig 26+28).
  Sign along the long axis still unresolved.
- Thermal: **0.1 mm/°C** drift even with autocal; autocal runs only at stream
  start — set `vl53l8cx_set_VHV_repeat_count()` for periodic recal once haptic
  motors (self-heat) run alongside ranging.
- 4×4 is spec'd ~2× tighter than 8×8 at range (±3-4% vs ±5%) — the mode we already
  stream.

### Lessons
- A residual that survives R, t, scale, and per-zone bias is telling you the
  *forward model* is wrong, not the parameters. List what each hypothesis would
  predict for the residual's **structure** (per-zone? per-pose? tilt-coupled?)
  before fitting anything.
- Two contradictory measurements can both be right. "What exactly does each one
  measure?" resolved a week-long 34°-vs-45° fight in one evening.
- Model-order sweeps (KB1→KB4) at identical RMS are the cheap, decisive test for
  extrapolation error — RMS itself carries no information about unsampled regions.

---

## 2026-08-16 — Stage 3 extrinsics: CAD geometry measured, first ToF↔camera calibration, and two of my own bugs

Long session. Took the pod from "nobody remembers how it was wired" to a measured
ToF→camera transform, via a rewire, a full CAD geometry survey, a working calibration
capture rig — and several false alarms that were all model errors, not hardware.

### Wiring recovered after the helmet remount
Everything had been unplugged to mount onto the bike helmet. Rebuilt the map from the
**firmware and the flashed ELF**, not from docs.

- Both ToF verified ranging on new pins: **A = SDA6/SCL7/PWREN4**, **B = SDA15/SCL16/PWREN5**.
- **The IMU runs I²C, not SPI.** The ELF contains `bno08x_init`, `sh2_open`,
  `i2c_master_transmit` ×7 and **zero** SPI symbols; a repo-wide sweep for
  `driver/spi_master.h`, `spi_bus_initialize`, `SPI2_HOST` matches nothing. The SPI work
  is real but older and on an **ESP32-C6 bench rig** (`docs/imu-bno085-bringup.md`).
  Confirmed physically: PS1 = PS0 = GND, the I²C strapping.
- **Lesson:** when memory and docs disagree, the compiled binary is the tiebreaker.
  Symbol presence in the ELF is not opinion.

### "Both sensors dead" — it was power, and the failure symmetry said so
Neither sensor answered on either bus; every address scan came back empty.

- **Root cause:** sensors unpowered.
- **The diagnostic that mattered:** *both* buses failing identically. Two independently
  wired sensors don't fail the same way by coincidence — that points at something shared
  (power, ground, rails), never at the data pins. Saved re-checking SDA/SCL.
- Full map written up in `docs/WIRING.md`.

### Black foam board vs white wall — measured instead of assumed
I claimed black would be too IR-absorbing at 940 nm. Built a surface-quality mode into
`tof_pin_test` reporting valid-zone count, frame jitter, sigma, and the sensor's own
**reflectance** estimate.

| Sensor B, same sensor | black board @756 mm | white wall @958 mm |
|---|---|---|
| valid zones | **16/16** | 12.8/16 |
| frame-to-frame | **5.76 mm** | 7.50 mm |
| reflectance | 9.4% | 56.3% |

- The board **is** dark at 940 nm (9.4%) — but at 76 cm it returns *more* signal
  (30.4 kcps/SPAD) than a 60%-reflective wall at 2.7 m (14.1). Signal falls as 1/r²;
  distance dominates reflectance.
- The white wall dropped 15% of its zones to **specular reflection** — a semi-gloss wall
  throws light away at the oblique angles our ±22.5° sensors view it from. Matt-and-dark
  beat bright-and-shiny.
- **Lesson:** visible colour does not predict near-IR behaviour, and the sensor reports
  its own reflectance estimate if you ask for it.

### CAD geometry: both ToF boresights measured to 0.003° of design
Measured PCB corners in SOLIDWORKS, derived full right-handed frames. Stored in
`cad/extrinsics_measured.json`; `docs/extrinsics_solve.py` re-derives every stored value
from the raw points so they cannot silently drift.

- Rectangle test on the right sensor: opposite sides equal, **diagonals within 0.022 µm**,
  4th corner **0.00 µm** off-plane, corner angle **90.0000°**.
- Both boresights within **0.003°** of the designed ±22.5° yaw + 22.5° group tilt.
- Both boards' up-axes identical to 4 dp and equal to `(0, cos22.5, sin22.5)`.
- **In the camera frame both sensors are PURE YAW** — pitch ≈ 0.0001°. The group tilt is
  common to camera and sensors so it cancels. The rigid-group construction verifying
  itself; a per-part tilt would leave residual pitch.
- **Trap recorded:** both sensors must use the board's *own left edge*, which is outboard
  on one and inboard on the other. Using mirror-corresponding edges flips the roll while
  every other check still passes.

### Bug #1: distance is PERPENDICULAR, not slant
Calibration residuals showed a strong radially-symmetric pattern — corners −14 mm, centre
+14 mm — recurring across poses (correlation 0.64). Chased a warped board, a radial sensor
bias, and crosstalk before testing the obvious.

- **Root cause:** treated `distance_mm` as slant range along the zone ray and computed
  `p = distance × unit_ray`. It is the **perpendicular (Z) distance**; correct form is
  `p = z × [tan(az), tan(el), 1]`.
- **Evidence:** same 23 poses, two interpretations — slant gives 12.02 mm plane rms and a
  −36.14 mm false dome; perpendicular gives **3.83 mm rms and −2.93 mm bow**, i.e. noise.
- **Cost:** a hunt for a warped board and a phantom sensor defect, plus false
  "zone off the board" flags in the capture tool.
- **Firmware implication, STILL UNFIXED:** `main.c:142` asserts "that stays as raw slant"
  and `compute_row_cos_table()` multiplies by `cos(zone_elevation + mount_pitch)`. If the
  value is already perpendicular, the zone-elevation half of that correction is applied to
  something that does not need it. The mount-pitch half is still required.
  **Live in the haptics and `/api/status` today.**
- **Lesson:** a radially-symmetric residual is a *geometry model* signature, not a defect
  signature. Test the model before blaming the hardware.

### Bug #2: camera frame x_right pointed the wrong way
The solve came back **179° from the CAD prior**, and I briefly concluded the sensor
identity mapping was backwards. It wasn't.

- **Root cause:** built the camera's `x_right` toward assembly +X. That is the wearer's
  **left**; image-right for a forward-facing camera is the wearer's **right** = −X. The
  wrong sign flipped x and y together — a 180° roll about the optical axis.
- **Derivation to keep:** right-handed with +Z forward and +Y up means a person facing +Z
  has their right along `Z × Y = −X`.
- **Fix:** corrected frame → rotation agreement went **179° → 2.0°**.
- **Lesson:** two opposite "left" conventions ran through the whole session —
  viewer-facing vs wearer-facing. Nearly every sign error traced back to it.
  Name the observer, not the side.

### Sensor identity — the error that cannot be caught downstream
`Sensor A` (pins 6/7/4) = **wearer's LEFT** = CAD `tof_right` (X = +18.67).

- Confirmed two independent ways: a hardware wave test, and from the axes (+X is
  screen-right viewing the front, i.e. the wearer's left; `tof_right` sits at X = +18.67).
- Get this backwards and every depth point lands **mirrored** while every geometric
  self-check still passes. Only visible in fused output.

### Calibration rig + first result
Built `camera/tof_calib_capture.py` (auto-capture on stillness + pose novelty, live
plane-residual colouring, live board-bow readout) and `camera/tof_calib_solve.py`.

- Auto-capture matters: a novelty gate (12°/80 mm) stops you collecting ten
  near-identical poses that look like ten measurements but constrain like one.
- **Colour zones by residual from a *curved* fit, not a plane.** With any board bow the
  corner zones sit ~14 mm off a plane while being perfectly on the board, and a flat-plane
  test flags them as off-board. A zone that has genuinely missed the edge is out by
  hundreds of mm.
- 17 poses, all 16/16 valid, condition number 4.0.
- **Result: rms 4.37 mm against a 3.08 mm noise floor, rotation 1.80° from CAD.**
- **The entrance pupil fell out of it** — 15.3 mm behind the CAD lens-face point, along
  camera +Z. Predicted in advance as the one term CAD structurally cannot see. Fixing `t`
  at the CAD value *raises* rms 4.37 → 10.14, so the data genuinely wants it.

### The 34°-vs-45° field: a long dead end, closed by physical measurement
The solver wanted a **34° zone field** where DS14161 says 45. Reported as a finding;
rejected twice by the user, correctly.

- Ruled out: warped board, radial bias, crosstalk (no cover glass; UM3109 §3.2 scopes it
  to a protective window), distance offset (degenerate — needs an absurd −79 mm),
  checkerboard scale (2.7%, wrong direction), 4×4 mode shrinking the field (nothing in
  UM3109 §4.3), the documented lens flip (§2.2 — real, but pure sign), all 4 rotations,
  transpose, and apex offset.
- **UM3109 §2.2:** the Rx lens "flips (horizontally and vertically) the captured image",
  so zone 0 sees the **top right** of the scene. Real, but mathematically identical to a
  sign change on the field — explains orientation, not magnitude.
- **Four probe attempts failed for the same reason each time — the ToF was seeing
  something other than the probe:** motion differencing tracked the whole arm while the
  ToF reported the hand; torch tracking failed because auto-exposure stops down; the
  checkerboard was taped to a 508 mm foam board covering >100% of the field; then the
  operator's body sat behind the sheet at the same depth.
- **What worked: checkerboard on a tripod, pod in hand.** Nothing else at that depth.
- **Verdict — column c0, the best-determined:**

| row | measured | agreement |
|---|---|---|
| r0c0 | −16.00 | 56.1% |
| r1c0 | −17.50 | 53.9% |
| r2c0 | −17.75 | 65.1% |
| r3c0 | −17.50 | 64.8% |

  mean **−17.19°, spread 0.72°**. Datasheet predicts −16.88 (**0.4° away, inside the
  spread**); the solver predicted −12.84 (**4.35° away, 6σ out**).

- **The datasheet is right. The pod has NO blind wedge** — inner edges meet at the camera
  axis as designed, zero-seam geometry intact. The 34° was the solver absorbing a model
  error not yet located.
- **Lesson:** a fitted parameter contradicting the datasheet by 25% is a bug hypothesis,
  not a finding. And a parameter degenerate with two others (offset, apex) cannot be a
  measurement however sharp its profile looks.

### Open
1. **Firmware pins + haptics move** — `main.c` still expects 1/2/5 and 41/42/40, and the
   ToF sensors now occupy the buzzer and all three motor pins. GPIO 1/2/41/42 are free.
2. **The cos-table double-correction** (bug #1) — live in haptics today.
3. **`MOUNT_ROTATION_DEG = 270` and `MOUNT_PITCH_DEG` are stale** — set for the old
   stacked mounting, not the ±22.5° pair.
4. **Sensor B not yet calibrated** — same procedure, `--sensor B`.
5. **Residual model error** — with FOV pinned at the datasheet 45°, rms is 7.96 mm against
   a 3.08 mm noise floor. Something is still unmodelled.
6. **SPAD offset** (1.72 mm along board-right, DS14161 Fig. 28) not yet applied.

---

## 2026-06-08 — Magnetometer A/B → mag-free decision, FREERTOS_HZ bug, drift cal

Resolved the IMU yaw-drift question by **measuring** instead of guessing, then fixed a
streaming bug it exposed and added drift-reducing calibration. End state: mag-free
**AR/VR-Stabilized Game Rotation Vector**, reliable streaming, dynamic yaw drift cut
~63%.

### The magnetometer A/B — why we went mag-free
Question (user's, fair): the motors are ~5 cm from the IMU through plastic — surely too
far to disturb a magnetometer? Tested it. Captured yaw + the BNO085's own mag accuracy
status (datasheet §3.1.5) sitting still, motors OFF vs ON, after a figure-8 calibration:

| Metric | motors OFF | motors ON |
|---|---|---|
| Mag accuracy | High (3), 100% | **Low (1)**, 897/921 samples |
| Heading uncertainty | 4.8° | **39°** (peak 59°) |
| Yaw noise (std) | 0.46° | 9.46° |
| Max step jump | 0.14° | **59.8°** |

The running motors' rotor magnet makes a **time-varying** field the fusion can't model
(static hard-iron it could). The chip's own confidence collapsed and it threw a ~60°
heading **jump** — which would land exactly during an obstacle alert. **Scale check:**
Earth's horizontal field here ≈ 18 µT; just ~1–3 µT of fluctuating stray field corrupts
heading, and a coin ERM motor at 5 cm plausibly makes a few µT (dipole, 1/r³). So the
"too far to matter" intuition was wrong at this spacing. **Decision: mag-free**
`SH2_ARVR_STABILIZED_GRV` (datasheet §3.1.6 p.39 literally recommends Game/AR-VR RV for
head-tracking in disturbed fields). Lever to reclaim the mag later = distance (1/r³).

### Bug — `FREERTOS_HZ=100` made the IMU task spin and starve the ToF loop
- **Symptom:** intermittent "no `DATA:`/`Q:` on this boot" while the IMU heartbeat kept
  climbing — i.e. the IMU service task ran but the ToF ranging loop never streamed.
  This was almost certainly the long-standing "~20% warm-reboot init flake."
- **Root cause:** `CONFIG_FREERTOS_HZ=100` → 10 ms tick → the service task's
  `vTaskDelay(pdMS_TO_TICKS(2))` computes `0.2 → 0 ticks` = **no delay**. The task
  free-spun (~2376 service calls/s measured, not the intended 500), monopolising the
  shared-I²C mutex and starving the ToF loop (prio 5) on unlucky scheduling boots.
- **Fix:** `CONFIG_FREERTOS_HZ=1000` (in `sdkconfig` + `sdkconfig.defaults`). The 2 ms
  delay is now real → the task paces at ~500 Hz and leaves the bus free. Fresh-boot
  streaming went from 0/3 to reliable; hub stays alive.
- **Lesson:** `pdMS_TO_TICKS(small)` silently truncates to 0 at a coarse tick rate —
  a "delay" that doesn't delay. Check the tick rate before trusting sub-10 ms `vTaskDelay`.

### Drift-reduction calibration (mag-free)
Mag-free yaw only drifts under motion (sitting still on a table the BNO085 auto-nulls the
gyro zero-rate offset, §3.1.3 — measured ~0°/min). Added in `bno08x_init`:
`sh2_setCalConfig(SH2_CAL_ACCEL | SH2_CAL_GYRO)` (gyro ZRO removal cuts drift, accel
anchors pitch/roll, mag OFF) and `sh2_setDcdAutoSave(true)` (persist calibration across
reboots, §3.4). Measured with a repeatable protocol (flat, two physical stops, 60 BPM
metronome, 40 s sweep, return to a marked reference): **drift +2.24° → +0.82°** (~63%,
matched ~195° excursions, N=1). DCD-across-power-cycle benefit still to verify.

### Files
- `components/bno08x/bno08x.c` — `SH2_ARVR_STABILIZED_GRV`; `setCalConfig` accel+gyro +
  `setDcdAutoSave`; `arvrStabilizedGRV` decode; `bno08x_get_status()`.
- `sdkconfig` + `sdkconfig.defaults` — `CONFIG_FREERTOS_HZ=1000`.
- `main/main.c` — `Q:` decoupled from the ToF frame gate (streams every loop iteration,
  6 fields incl. status).
- `visualizer/imu_capture.py` (mag A/B), `imu_drift_dynamic.py` (repeatable dynamic-drift
  test), `visualizer_dual.py` (`Q:` parser tolerant of extra fields).

---

## 2026-06-07 (later) — Magnetometer test mode + two streaming/serial gotchas

Switched the IMU to the **9-axis mag-fused Rotation Vector** to test whether the
magnetometer can kill the yaw drift of the 6-axis Game Rotation Vector (user asked;
datasheet §2.2.4 calls the mag-fused RV "the most accurate orientation estimate").
Now streams `Q:w,x,y,z,status,headacc_rad` — `status` 0..3 = mag calibration accuracy
(datasheet §3.1.5), `headacc_rad` = estimated heading accuracy. Uncalibrated, the chip
reports `status=0` and `headacc=π` (≈180°) — that's the datasheet's "no heading yet"
sentinel, **not** a bug; both improve after a figure-8.

### Bug — `Q:` (IMU) was gated behind the ToF frame, so a ToF stall killed IMU stream
- **Problem:** capture showed the IMU healthy (`hb: rv` climbing ~100 Hz) but **zero
  `Q:` lines**, and zero `DATA:`/`DATAT:`.
- **Root cause:** in `ranging_task`'s loop, `if (!got) { …; continue; }` (no fresh ToF
  frame) skipped the **rest of the loop, including the `Q:` block**. The IMU print was
  coupled to the ToF being ready — so any ToF stall silently took the IMU down with it.
- **Fix:** emit the `Q:` line **before** the `if (!got)` gate, every iteration,
  independent of the ToF. IMU and ToF now stream independently (verified: Q≈DATA≈DATAT
  ~28 Hz together).
- **Lesson:** keep independent data sources on independent emit paths; don't let one
  sensor's readiness gate another's output.

### Gotcha — never RTS-reset the USB-Serial-JTAG to start a capture
- **Problem:** the capture script pulsed RTS to reset the ESP on port open; it then hung
  forever on "waiting for IMU reports," and the port sometimes vanished (`FileNotFound`).
- **Root cause:** this board's serial is the ESP32-S3's **internal USB-Serial-JTAG**.
  An RTS reset reboots the chip, which **drops + re-enumerates the USB device** — the
  open handle goes stale, so the script reads a dead port. (A real external UART bridge
  survives this; the JTAG one cannot, because the bridge *is* the chip.)
- **Fix:** **don't reset** — just attach to the already-running stream (opening the JTAG
  port does not reset the ESP). Bonus: with no reset, the BNO085 keeps its calibration
  across capture runs (the firmware only soft-resets the hub on a real ESP reboot), so
  you calibrate once and can run motors-off / motors-on back-to-back.
- **Lesson:** USB-Serial-JTAG ≠ UART bridge. To force a clean reboot use `esptool`
  (`--before default_reset --after hard_reset`), not an RTS toggle on an open handle.

### Files
- `main/main.c` — `Q:` moved above the ToF `if(!got)` gate; now 6 fields with status.
- `components/bno08x/{bno08x.c,include/bno08x.h}` — `ROTATION_VECTOR` enable;
  `bno08x_get_status()` exposes accuracy + heading-accuracy.
- `visualizer/imu_capture.py` — attach-don't-reset capture; figure-8 calibrate phase
  then still-baseline record; motors-off vs motors-on A/B.
- `visualizer/visualizer_dual.py` — `Q:` parser tolerates the extra fields.

---

## 2026-06-07 — IMU fully working on the shared I²C bus (the full story)

The BNO085 now streams head orientation at **~100 Hz alongside BOTH VL53L8CX ToF
sensors** on the shared I²C_NUM_1 bus, and `Q:w,x,y,z` drives head orientation in
the visualizer. It took peeling back **three stacked, independent bugs** — each one
hid the next. All three + the dead ends are documented so this is debuggable if it
ever regresses. **The wiring was never the problem.**

### Bug 1 — wrong I²C address (0x4B → 0x4A)
- **Problem:** the probe ACKed at **0x4B** but no SHTP read ever decoded.
- **Root cause:** real address is **0x4A** (ADO grounded). The 0x4B "ACK" was a
  misleading write-only response.
- **Fix:** talk to 0x4A. **Lesson:** a write+ACK probe can lie — ground truth is
  *which address returns valid protocol data*, not which one ACKs.

### Bug 2 — the missed one-time SHTP advertisement (the `enable -> -2` wall)
- **Problem:** at 0x4A the handshake *still* failed — `sh2_getProdIds` silent,
  `sh2_setSensorConfig` returned **-2 (SH2_ERR_BAD_PARAM)**, `evt` stayed 0. Tell:
  it worked the **very first time** the board was freshly plugged in, then never
  again.
- **Root cause:** the BNO085 emits its SHTP **advertisement / reset-complete packet
  only ONCE, right after power-on.** Reflashing resets the **ESP, not the IMU** — so
  after boot #1 the advertisement was long gone, `sh2_open()` found nothing to read,
  no SHTP channels got set up, and `setSensorConfig` therefore had no control
  channel → -2.
- **Fix:** in `hal_open()`, send a **reset on the SHTP executable channel**
  (`{0x05,0x00,0x01,0x00,0x01}` = length 5, channel 1, cmd 1 = RESET) so the hub
  reboots and **re-advertises on every boot** — no manual power-cycle.
- **Lesson:** "works once after a physical unplug, dead on every soft reset" = a
  device that only advertises at power-on. Force the device reset in the HAL.

### Bug 3 — hub starvation during the ToF firmware upload (the low-rate / freeze)
- **Problem:** handshake fixed, but the IMU streamed a few reports then its rate
  collapsed/froze (`evt` stuck ~17, or `pkts` << `calls`).
- **Root cause:** `vl53l8cx_init()` uploads ~84 KB of ULD firmware over I²C — ~1 s
  during which the IMU got **zero servicing**. The BNO08x **self-starves** if it
  isn't serviced within ~1/10 of its report period (datasheet); a ~1 s gap killed it
  and no amount of fast servicing *afterward* brought it back.
- **Fix (three parts):**
  1. Bring the IMU up **AFTER** the ToF init, not before — no pre-ToF handshake means
     no starvation gap (the Bug-2 soft-reset makes the handshake work fine even with
     the idle ToF already on the bus).
  2. Give the IMU its **own ~500 Hz service task** — the main ranging loop is
     streaming-bound at ~33 Hz, far too slow to keep the hub alive.
  3. A **shared FreeRTOS mutex** serialises IMU vs ToF transactions on the bus.
- **Lesson:** the BNO08x is needy — service it continuously and fast or it stops.
  Never leave it unserviced through a long blocking init.

### Dead ends — DO NOT repeat these
- **`scl_wait_us = 20000`** (clock-stretch tolerance): I first blamed *and* then
  credited this for the handshake. It was **neither** — the handshake failure was
  Bug 2 (advertisement), not a stretch timeout. Left at default; a larger value is
  harmless but not the fix.
- **`i2c_master_bus_reset()` on every failed read:** thrashed the bus ~40 000×/s
  while the handshake was down. Removed.
- **Single-owner task** (service the IMU from the ranging loop, no 2nd task): killed
  the hard *stall* but the loop (~33 Hz) is too slow → hub starved (~2 Hz). Necessary
  insight, not sufficient alone.
- **Two-task + mutex on the loop reads only:** the IMU wedged during the *unmutexed*
  ToF init. Either the mutex must cover ALL shared-bus access, or the IMU must come up
  *after* init — we chose the latter (simpler, no managed-component edits).
- **Clock-matching both devices to 400 kHz:** irrelevant to all of the above.

### How it was found
One variable at a time + watch the chip's own heartbeat (`evt`/`pkts`/`calls`), plus
**two targeted web-research passes** that surfaced the two facts no amount of code
staring would reveal: *"advertises only once at power-on"* and *"self-starves if
under-serviced."*

### Files
- `components/bno08x/bno08x.c` — soft-reset in `hal_open`; `bno08x_init()` (handshake +
  block-until-reporting) + `bno08x_service()` + `bno08x_run_task()` (500 Hz task, mutex).
- `main/main.c` — IMU brought up after ToF init; `i2c1_mutex` shared with the ToF reads.
- `visualizer/visualizer_dual.py` — parses `Q:`; rotates the head-attached items by the
  quaternion; "Recenter IMU" zeroes the pose (game-RV yaw is arbitrary + drifts).
- *Cleanup TODO:* `managed_components/.../platform.{c,h}` got an unused
  `VL53L8CX_SetBusMutex` from the abandoned platform-mutex approach — inert, remove on
  next pass. Also strip the `hb`/`IMU PROBE` debug logging.

---

## 2026-06-06 — Dual-sensor integration, debug switch, visualizer overhaul, IMU bring-up

### System state at end of session
- **Two VL53L8CX ToF sensors** live on separate I²C buses:
  - Bottom (`I2C_NUM_1`, SDA=GPIO1, SCL=GPIO2), mounted ~30° **down** → ground/low obstacles.
  - Top (`I2C_NUM_0`, SDA=GPIO41, SCL=GPIO42), mounted ~5° **up** → head/overhead.
  - No address collision (both at 0x29 but on separate buses). Shared directional haptics + buzzer.
- **BNO085 IMU** wired onto the bottom I²C bus, **detected at 0x4B** (driver not yet written).
- Streams `DATA:` (bottom), `DATAT:` (top), `SIGMA:`, `STATUS:` over TCP:3333 + UART; `/api/status` JSON + phone heatmap viewer at `http://<ip>`.
- Desktop 3-D visualizer (`visualizer/visualizer_dual.py`) overhauled (see below).

### Haptic-pause debug switch (GPIO17)
- **Goal:** a physical switch to silence motors + buzzer while debugging the sensor.
- **Design:** SPDT, COM→GPIO17, one outer→GND, third pin empty; firmware uses the ESP's **internal pull-up**, so `HIGH=on`, `LOW(GND)=paused`. Switch carries **no power rail** — only ground — by design.
- **Problem:** with the switch wired COM→GPIO17, one outer→GND, one outer→**3.3V**, flipping it intermittently **bricked the ESP until a full power-cycle.**
- **Root cause:** putting both 3.3V *and* GND on the switch means a make-before-break (or bouncing) contact momentarily **shorts 3.3V→GND through the switch → brownout → USB-Serial-JTAG wedges → only a power-cycle recovers.**
- **Fix:** remove the 3.3V wire entirely. With the internal pull-up supplying "high," the switch can only ever connect GPIO17 to GND or let it float high — nothing to short. **Lesson:** a logic-level switch should never bridge a power rail; let the MCU's pull-up provide the high side.

### Firmware gotcha: `HAPTIC_TEST` left enabled
- **Problem:** after flashing, the device ran a motor-pulse test and **skipped sensor ranging entirely** ("sensor ranging SKIPPED").
- **Root cause:** `#define HAPTIC_TEST 1` had been left on from a 2026-06-05 motor-ID session ("set back to 0 after" — never done).
- **Fix:** set `HAPTIC_TEST 0` / `HAPTIC_ID_MODE 0`. **Lesson:** temporary build flags need a hard "revert" checkpoint; a stray `1` cost a confusing debugging detour.

### Visualizer overhaul (desktop 3-D)
- **Launch gotcha:** the PyQtGraph window *did* launch from the agent's tooling but opened **behind** other windows (and in a non-foreground session), so it looked like "it never launched." **Fix:** verify via Win32 `EnumWindows` (the window title also reports stream state) and force-foreground it; don't assume a launch failure. Burned ~an hour misdiagnosing this as session-0 GUI isolation.
- **Lag at >500 frames:** per-frame Qt signal accumulation. **Fix:** reader thread writes a shared "latest frame" dict; the GUI timer pulls only the newest → fixed cost, no backlog.
- **"Noisy bumps" / hard to read:** raw per-zone distance jumps were amplified by a connect-the-dots surface mesh. **Fix:** the firmware already streams `SIGMA:`/`STATUS:` per zone — now the viz **drops low-confidence zones** (STATUS ∉ {5,6,9}) and **high-noise zones** (SIGMA > threshold) *before* rendering, plus stronger temporal EMA.
- **Readability research:** ST/RealSense/LiDAR practice all flatten to fixed 2-D (heatmap / range-image / top-down) for *live* reading; a free-floating 3-D point cloud is good for offline scanning, poor for at-a-glance distance. Kept the 3-D (user preference) but added depth aids.
- **Final 3-D form (user-directed):** clean points at measured positions + **trace rays** from the helmet to each point (length = distance, no inter-point net); faint FoV frustums; head model + floor plane; hot→cool distance colormap; **preset-view buttons** (Front / 3⁄4 / Top / Side); FPS + nearest-L/R readout. Note: forward axis = GL +Y, so "front" camera sits on +Y looking back.
- **TCP-client clog:** repeated viz relaunches + device resets left stale TCP clients on the ESP (MAX 4) → new viz got ~1 FPS. **Fix:** device reset clears the client table; run a single viz instance.

### IMU bring-up (BNO085 over I²C)
- **Protocol selection:** the BNO085 picks I²C/UART/SPI from strap pins **PS1/PS0, read only at power-on.** I²C = **PS1=0, PS0=0** (both GND). (Prior SPI work used PS1=1/PS0=1.)
- **Problem:** not detected on the bus despite "correct" wiring.
- **Root causes (two):**
  1. Wired to GPIO1/2 (**bottom** bus) while the probe only checked GPIO41/42 (**top** bus) — added a probe to both buses.
  2. PS pins left from the earlier SPI config → chip booted in the wrong protocol. And an **ESP soft-reset does not power-cycle the IMU**, so the wrong mode persisted until a true power-cycle re-latched the PS pins.
- **Fix:** PS1=PS0=GND + full power-cycle → **BNO085 ACKs at 0x4B.**
- **Board-mapping lesson:** the cheap GY-BNO08X clone has an **unreliable silkscreen** — SDA/SCL had to be swapped from the labels, and ADO reads 0x4B despite being grounded (onboard pull-up or inverted mapping). **The I²C probe is ground-truth; trust the address that ACKs (0x4B), not the silkscreen.**
- **Driver status:** SH-2/SHTP is required (no simple register read on BNO085). CEVA `sh2` C sources copied to `components/bno08x/sh2/`. The available `esp32_BNO08x` library is **SPI-only**, so the I²C SHTP transport (HAL: open/read/write/getTimeUs, with SHTP header-peek + chunked cargo reads) must be written from scratch. **Next session.**

### Backlog logged
- **ToF↔ToF mutual interference** (two sensors' 940 nm emissions cross-talking) — investigate right after the IMU works. See `photos/test_rig/future_test_ideas.md`.

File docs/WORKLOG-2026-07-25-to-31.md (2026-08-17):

# Work log — Phase 2 camera bring-up → calibration → mount CAD

**2026-07-25 to 2026-07-31.** Problem → Root cause → Fix → Lesson, per the project's devlog convention.

---

## Summary of what changed

| Milestone | Status |
|---|---|
| Camera alive on USB | ✅ Done |
| Lens focused + locked | ✅ Done |
| **Fisheye calibration (K, D)** | ✅ **RMS 0.30 px** |
| **Real field of view measured** | ✅ **H 119.6°, V 63.1°, D 144.0°** |
| Mount geometry locked | ✅ All 22.5° |
| Component CAD (ToF, camera, HC-SR04) | ✅ STEP + STL |
| Sensor pod CAD | ✅ First revision, 60 g |
| Helmet interface CAD | ⬜ Blocked — helmet not chosen |
| Electronics box CAD | ⬜ Blocked — board/battery spec |
| Stage 3 ToF↔camera extrinsics | ⬜ Next |
| Stage 4 fusion overlay | ⬜ The goal |

---

## STAGE NUMBERING (this supersedes all earlier numbering)

| # | Stage | Produces | Status |
|---|---|---|---|
| 0 | Camera alive | A picture | ✅ |
| 1 | Focus + lock lens | A lens that cannot shift | ✅ |
| 2 | Calibrate lens (intrinsics) | **K, D** | ✅ |
| 3 | Align ToF to camera (extrinsics) | **R, t** | ⬜ |
| 4 | Project + overlay | **FUSION WORKING** | ⬜ |
| 5 | Detection-gating | "person, 1.8 m, left" | ⬜ |
| 6 | Mono-depth | Dense depth across 140° | ⬜ |

---

## 1. Camera bring-up

**Problem.** Camera enumerated but every frame was pure black.

**Root cause.** Two separate things. First the lens was physically covered. Then, once
uncovered, **1920×1080 MJPEG still returned an all-zero payload** while 1280×720 and
YUY2 640×480 worked perfectly.

**Investigation (the honest version).** My first "proof" was wrong: I used
`CAP_PROP_CONVERT_RGB=0` to grab a "raw" payload and found 6.2 MB of zeros with no JPEG
marker. **That test was invalid** — OpenCV's DirectShow backend pins output to RGB24 and
never hands back raw MJPEG, so I was reading uninitialised memory, not the device. The
load-bearing evidence turned out to be **`ffmpeg -c:v copy`**, which writes the camera's
own JPEG bytes to disk with no decoder in the path: at 1080p it never produced a single
file, at 720p it worked. That rules out every decode-side explanation.

**Real cause.** The module's firmware declares **uncompressed bitrates inside its MJPEG
descriptors** — 1080p MJPEG reports `dwMaxBitRate 995328000`, which is exactly
`1920×1080×2 bytes×30×8`, the YUY2 figure copy-pasted. Per UVC 1.5 §4.3.1.1.1 the host
reserves bandwidth *from that advertised figure*, so it tries to reserve ~10× what is
needed and allocation fails. The stream starts and delivers nothing. Linux patches this
exact defect with `UVC_QUIRK_FIX_BANDWIDTH`; Vimicro's other USB IDs carry that quirk in
`uvc_driver.c` and **ours (0x0AC8:0x0346) was never added. Windows has no equivalent.**

**Fix.** Capture at **MJPG 1280×720**. Costs nothing real — detectors downscale to ~640
anyway and the ToF is a 4×4 grid.

**Lessons.**
- **`-c:v copy` is the honest test on Windows.** It bypasses every decoder. Do not trust
  `CAP_PROP_CONVERT_RGB=0` on the DSHOW backend to give raw bytes.
- Throughput was never the limit: USB 2.0 HS allows 24.6 MB/s per isochronous endpoint;
  1080p30 MJPEG needs only ~12.4 MB/s. **A wrong number in a descriptor broke it, not physics.**

## 2. There is no datasheet for this camera

**Problem.** We had been carrying "~109° H / 67° V" as if it were spec.

**Root cause.** It was an **extrapolation from sibling products**. HBVCAM publishes no
datasheet for the "WA" variant at all — verified negative, it's a reseller SKU.

**Fix.** Ground truth from the device's own UVC descriptors
(`ffmpeg -f dshow -list_options`), and the real FOV from calibration.

**Lesson — now a standing rule.** *"For every single piece of hardware we work with you
must always have the official spec sheet before making any inferences."* Where none
exists, say so explicitly and get ground truth from the device — never silently
substitute a sibling's datasheet.

## 3. The live-capture tool kept freezing

**Problem.** The checkerboard capture tool froze the instant it detected a board.

**Root causes — three, stacked.**
1. **A console window stuck in QuickEdit "select" mode.** On Windows, clicking inside a
   console *pauses the program*; the next `print()` blocks forever. The script printed on
   every capture → froze on first detection. **This was the main one.**
2. **DirectShow frame-queue backup.** When detection made the loop slower than 30 fps,
   frames queued in the driver and every `read()` returned an older frame — it looked
   frozen while actually showing the past.
3. Full-resolution corner detection plus synchronous PNG encoding (~200 ms) in the loop.

**Fixes.** Launch with `pythonw.exe` (no console to click into); a reader thread that
keeps only the newest frame; PNG encoding on a worker thread.

**Then I over-corrected:** dropping detection to quarter resolution made the frame
320×180, where the board's squares were too small to detect at all. Reverted.

**Lesson.** "It froze" had nothing to do with compute — the user's instinct that a GPU
should fix it was reasonable but wrong. `findChessboardCorners` is CPU-only in OpenCV and
there is no CUDA version. **Diagnose the block before optimising the work.**

## 4. Abandoned the hand-rolled live tool

**Problem.** The interactive capture tool kept needing fixes.

**Research verdict.** **No free turnkey Windows GUI does fisheye + live capture.**
OpenCV's own `interactive-calibration` app is **pinhole only** (verified: zero fisheye
references in its source). ROS `camera_calibration` has good fisheye support but needs
ROS. Kalibr is ROS-bound, BabelCalib is MATLAB. caliscope is free and does real fisheye
but wants ChArUco and video files. calib.io Calib is the only true GUI match — paid, with
a 14-day trial.

**Fix — delete the hard part.** `record_calib.py` records a video with a countdown and a
live preview and **no detection in the loop**; `extract_from_video.py` does detection
offline where nothing can race. The solver was never the janky part — `cv2.fisheye` is
what every tool wraps.

**Lesson.** When a UI keeps breaking, remove the UI rather than harden it.

## 5. Calibration — first attempt failed, second succeeded

**Attempt 1: RMS 5.52 px, garbage output** (180° diagonal FOV, optical centre 58 px off).

**Root cause.** The board filled only **0.6–2.4%** of the frame in every view — roughly
10 px per square. Corners cannot be localised at that scale and the distortion model had
nothing constraining it.

**Fix.** Minimum-fill and minimum-sharpness filters in the extractor, and hold the board
closer. *(My first threshold, 8%, rejected every frame — a letter-size board on a 140°
lens only reaches 1.3–7.4% at normal distances. Measured the actual distribution and set
it to 3%.)*

**Attempt 2: RMS 0.61 px**, then **0.30 px** after dropping the two worst-reprojection
frames (1.18 and 0.80 px).

### ✅ Final calibration — `camera/calibration_720p.npz`

```
MJPG 1280x720, cv2.fisheye (Kannala-Brandt), 19 views, RMS 0.3006 px

fx = 669.823   fy = 670.075        cx = 620.953   cy = 335.169
D (k1..k4) = [-0.079359, -0.006644, 0.016116, -0.007523]

MEASURED FOV:  horizontal 119.58°   vertical 63.12°   diagonal 144.02°
```

**Why we trust it.** The diagonal came out **144.0° against a claimed 140°** — an
independent check the solver never saw. `fx` and `fy` agree to 0.04%, so pixels are
square and the fit is clean. The earlier 158.8° was the two bad frames.

**Consequence.** We had been assuming ~109° horizontal. It is **119.6°** — about 10°
wider. That changes how much of the camera view the ToF fan covers.

**⚠️ K is resolution-dependent. Always capture at 1280×720 or recalibrate.**

## 6. Mount geometry locked

- **ToF ×2: ±22.5° yaw, 22.5° down.** 45° apart → 90° combined, edge to edge. *Not* 45°
  off-centre each — that opens a 45° blind hole dead ahead.
- **Camera: 0° yaw, 22.5° down.**

**Why the camera also sits at 22.5°** (`docs/camera_tof_overlap.png`): it centres the ToF
fan in the frame with **symmetric 9.1° margins**, so depth occupies the middle 14–86% of
the image, away from the edges where fisheye distortion is worst and our calibration is
least constrained. **A 20° tilt is worse, not better** — it drops the bottom margin to
6.6° and pushes the ToF band to 90% of frame height. The user's instinct (keep clear of
the bottom edge) was right; the direction was inverted.

**Vertical coverage at 22.5° down**, sensor at 1.6 m (`docs/tof_tilt_chart.png`): fan
spans 0°–45° below horizontal, floor covered from 1.6 m out, and at 2 m+ a person is
seen floor-to-1.6 m. 22.5° is the largest downtilt that keeps the top ray horizontal.

**Known gaps:** nothing above 1.6 m; nothing below 0.60 m at 1 m range.

## 7. Sensor research

**SATEL-VL53L8 — ST publishes no dimensioned drawing.** The Gerbers and STEP model are
the only mechanical sources. **Downloaded ST's STEP and measured it directly:**

| | Value |
|---|---|
| PCB | **51.500 × 19.500 × 1.578 mm** *(caliper said 51 × 19 — agrees)* |
| VL53L8CX package | X 4.910–7.940, Y 6.550–12.950, top 1.750 above PCB |
| **Pins protrude BELOW PCB** | **10.060 mm** ← drives pod clearance |
| Tallest above PCB | 8.482 mm |

**Cross-check:** the datasheet's optical axis (1.615 mm from the long edge, 0.100 mm off
package centre) is reproduced exactly by the STEP placement. Two independent ST sources
agreeing.

**The board snaps apart** (documented perforations, mini-PCB). *User chose to keep the
full board — only a few grams.*

**AN5939 window rules** (only if a window is ever used): air gap < 0.5 mm without a
gasket, gap + glass < 1.5 mm, two circular apertures **concentric with the optical
centres**. **We use open apertures instead** — simplest compliant option.

### ❌ HC-SR04 is a poor overhead detector

- A **bare branch reflects ~30 dB weaker than a flat plate** and fills 3–5% of the beam at
  2–3 m. **No source demonstrates reliable single-branch ranging.**
- Even flat lintels are marginal: the specular window for a 30 cm lintel is **±1.6°**, and
  *larger* flat surfaces are narrower still. Head pitch while walking swings them in and out.
- **Two sensors = 8.3 Hz each** after the mandatory 60 ms round-robin. Crosstalk's failure
  mode is a **false SHORT reading** — the worst kind on an alert device.
- The "15° beam" is marketing; no datasheet gives a dB point. Usable cone ~30°.
- Classic HC-SR04 **won't run at 3.3 V** and its ECHO is 5 V into a non-5 V-tolerant
  ESP32. **Use HC-SR04P / RCWL-1601** — 3.0–5.5 V, software-identical.
- Temperature: 340 m/s hardcoded ⇒ **±15 cm at 4 m** across Vancouver's range.

**Better option: LD19 / STL-19P 2D lidar (~$70–99), scan plane VERTICAL.** A sweeping
plane physically cannot miss a horizontal branch by pointing between it — exactly the
ultrasonic failure mode. *User chose HC-SR04 as a cheap first pass, which is fine — just
don't build the head-protection promise on it.*

## 8. CAD

CadQuery 2.8.0. Parametric Python → STEP (editable in Onshape/SOLIDWORKS) + STL.

**`cad/components.py`** — every component, all dimensions tagged
`[ST-STEP]` / `[DS]` / `[CALIPER]` / `[TBD]`:
- `tof_satel_vl53l8` — exact, from ST's model
- `camera_hbv1716wa` — 38 × 38 confirmed by caliper; hole pitch, depth, lens Ø still `[TBD]`
- `hcsr04` — datasheet; can pitch `[TBD]` (scaled off a drawing, never dimensioned)

**`cad/sensor_pod.py`** — the precision part. **132 × 62 × 46 mm, ~60 g in PLA.**

*First revision came out at **359 g** — a solid block. Shelling it to a 2.4 mm wall before
cutting the pockets took it to 60 g with identical outer geometry, so the sensor angles
are untouched. **Always check printed mass on a wearable.***

**Why one part:** Stage 3's calibration holds only while the ToF and camera cannot move
relative to each other. Everything optical lives in this one body; the helmet interface
is separate, so changing helmets never invalidates the optics.

---

## Open items

**Blocking the CAD**
- Camera calipers: **hole pitch (28 vs 32?), depth (17.5 vs 25?), lens barrel Ø, PCB thickness**
- Helmet: bike helmet recommended (vents = anchor points, no drilling), **not confirmed**
- Electronics box: ESP32-S3 + haptic drivers + IMU + ToF pull-ups + USB hub — **need the
  specific S3 board, the battery, and what the USB hub is for.** The S3 cannot host this
  camera; vision runs on a laptop, later a Pi 5.

**Engineering**
- ~~Camera dropping off the USB bus~~ — **RESOLVED 2026-07-31: those were manual unplugs,
  not a fault.** No spontaneous disconnects have been observed. Not a design risk.
- OV2710 stable-image range is **0–50 °C** (datasheet Table 8-2); it functions to 70 °C
  with degraded quality.

**Next**
- **Stage 3** — ToF↔camera extrinsics. Doesn't need the mount finished; a temporary rigid
  fixture proves it, and it tells us what alignment precision the mount actually needs.
- **Stage 4** — the fusion overlay.

---

## Files created

**Camera / calibration** — `camera/`
`README.md` · `GLOSSARY.md` · `CALIBRATION-RUNBOOK.md` · `checkerboard_8x11_20mm.pdf` ·
`make_checkerboard.py` · `camera_check.py` · `camera_live.py` · `camera_focus.py` ·
`shoot.py` · `record_calib.py` · `extract_from_video.py` · `calibrate_fisheye.py` ·
`calibration_720p.npz` / `.txt` · `undistort_preview.jpg`

**Docs** — `docs/`
`fusion-executive-summary.md` · `MOUNT-DIMENSIONS.md` · `SENSOR-MOUNTING-FACTS.md` ·
`tof_tilt_chart.py` / `.png` · `camera_tof_overlap.py` / `.png` ·
`datasheets/camera/HBV-1716WA-VERIFIED-SPECS.md` · `datasheets/tof/satel-step/J5866.step`

**CAD** — `cad/`
`components.py` · `sensor_pod.py` · `step/` · `stl/`

*Docs also mirrored to Obsidian: **Claude notes → Helmet Camera**.*

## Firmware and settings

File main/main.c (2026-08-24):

/**
 * VL53L8CX ESP32-S3 Distance Sensor Interface
 *
 * Streams DATA: + SIGMA: lines per frame over BOTH:
 *   - UART (printf / USB-CDC, ~115200 baud)
 *   - TCP (when a client is connected on TCP_PORT over WiFi)
 *
 * Hardware (SATEL-VL53L8CX breakout â†’ ESP32-S3):
 *   SATEL PWREN     â†’ GPIO_PWREN  (+ 10kÎ© pullup to 3.3V)
 *   SATEL MCLK_SCL  â†’ GPIO_SCL    (+ 2.2kÎ© pullup to 3.3V)
 *   SATEL MOSI_SDA  â†’ GPIO_SDA    (+ 2.2kÎ© pullup to 3.3V)
 *   SATEL NCS       â†’ 3.3V        (tie high = I2C mode)
 *   SATEL SPI_I2C_N â†’ GND         (selects I2C mode)
 *   SATEL VDD       â†’ 5V
 *   SATEL GND       â†’ GND
 */

#include <stdio.h>
#include <string.h>
#include <stdarg.h>
#include <stdbool.h>
#include <errno.h>
#include <math.h>

#include "freertos/FreeRTOS.h"
#include "freertos/task.h"
#include "freertos/semphr.h"
#include "freertos/event_groups.h"
#include "driver/i2c_master.h"
#include "driver/gpio.h"
#include "esp_log.h"
#include "driver/ledc.h"
#include "esp_wifi.h"
#include "esp_event.h"
#include "esp_netif.h"
#include "esp_system.h"
#include "esp_timer.h"
#include "esp_ota_ops.h"
#include "esp_http_server.h"
#include "nvs_flash.h"
#include "lwip/sockets.h"
#include "lwip/netdb.h"

#include "vl53l8cx_api.h"
#include "bno08x.h"
#include "wifi_credentials.h"

/* â”€â”€ Pin configuration â”€â”€â”€â”€â”€â”€â”€â”€â”€â”€â”€â”€â”€â”€â”€â”€â”€â”€â”€â”€â”€â”€â”€â”€â”€â”€â”€â”€â”€â”€â”€â”€â”€â”€â”€â”€â”€â”€â”€â”€â”€â”€â”€â”€â”€â”€â”€â”€â”€â”€â”€â”€â”€ */
/* ── 2026-08-16 REWIRE: left/right ±22.5° yaw pair, whole group 22.5° DOWN ──
 * Wiring is FINAL (user decision 2026-08-16, verified live by tof_pin_test).
 * Sensor A = wearer's LEFT  = CAD `tof_right` (the conventions are opposite —
 * see cad/SESSION-HANDOFF-2026-08-16.md before touching anything). */
/* Sensor A (wearer LEFT, streams as the primary grid). I2C_NUM_0. */
#define GPIO_SDA      GPIO_NUM_6
#define GPIO_SCL      GPIO_NUM_7
#define GPIO_PWREN    GPIO_NUM_4
/* Sensor B (wearer RIGHT). Second bus, I2C_NUM_1. */
#define GPIO_SDA2     GPIO_NUM_15
#define GPIO_SCL2     GPIO_NUM_16
#define GPIO_PWREN2   GPIO_NUM_5
/* ⚠ PROVISIONAL: buzzer/motors/IMU are NOT WIRED yet (removed in the helmet
 * remount). Their old pins 6/7/15/16 now belong to the ToF buses, so they are
 * parked on the freed pins below purely so the firmware compiles and drives
 * nothing real. USER WILL SUPPLY the actual pins when he wires them — update
 * these five defines then, and re-verify motors with the single-pin ID pulse. */
#define BUZZER_GPIO         GPIO_NUM_40  /* PROVISIONAL — not wired */
/* Debug pause switch: 3-pin SPDT, COM->this GPIO, one outer->GND, third pin
 * unconnected. Internal pull-up => HIGH = haptics ON, LOW (GND side) = paused. */
/* 2026-08-17: SWITCH DISABLED — GPIO 17 now drives the CENTER motor, and the
 * switch's input+pullup config was fighting the motor output (motor buzzed
 * continuously). The physical switch is not wired. Re-enable on a FREE pin
 * if it ever comes back. */
/* 2026-08-17 evening: switch RE-WIRED to GPIO 3 (next header pin after the
 * motors). COM(middle)->GPIO3, one outer->GND, internal pullup. GPIO3 is a
 * strapping pin but its JTAG-select role needs an eFuse burn we don't have —
 * safe as plain input. NOTE: when enabled, the physical switch OVERRIDES the
 * /api/haptics software toggle every frame. */
#define HAPTIC_SWITCH_ENABLED 1
#define HAPTIC_SWITCH_GPIO  GPIO_NUM_3
#define BUZZER_TEST         1            /* set 0 to silence */
/* Haptic motor bench test (Option B): when 1, app_main skips sensor ranging
 * and runs a motor ramp on HAPTIC_GPIO, but KEEPS WiFi + OTA alive so you can
 * OTA back to normal firmware. Set 0 for normal operation. See
 * docs/haptics-bringup.md. Uses LEDC channel 1 / timer 1 (buzzer owns 0/0). */
#define HAPTIC_TEST         0   /* 0 = sensor mode; 1 = run haptic test task */ /* TEMP: testing RIGHT motor 2026-06-05 — set back to 0 after */
/* When HAPTIC_TEST=1, HAPTIC_ID_MODE picks which task body runs:
 *   0 = original 3-motor sequence (CENTER alone -> RIGHT alone -> LEFT alone -> ALL)
 *   1 = identify mode: short bursts on HAPTIC_ID_GPIO only (helps map
 *       a single GPIO to its physical motor location on the helmet).
 * Change HAPTIC_ID_GPIO to HAPTIC_GPIO_RIGHT or _LEFT between OTA flashes
 * to ID the other two. */
#define HAPTIC_ID_MODE      0
#define HAPTIC_ID_GPIO      HAPTIC_GPIO_RIGHT   /* pulse this one to find it */
/* 2026-08-17: motors wired to "the next 3 consecutive header pins after the
 * ToFs" = GPIO 17, 18, 8 (DevKit left column: ...15,16,17,18,8...). WHICH
 * motor sits at which temple is unknown until the /api/motor ID test runs —
 * the CENTER/RIGHT/LEFT assignment below is a guess to be corrected then.
 * (GPIO 17 was reserved for the pause switch; switch is unwired, reassigned.) */
/* ✅ ID-VERIFIED 2026-08-17 19:15 by pulse test with motors mounted:
 *    GPIO 17 = LEFT temple, GPIO 18 = CENTER forehead, GPIO 8 = RIGHT temple */
#define HAPTIC_GPIO_CENTER  GPIO_NUM_18
#define HAPTIC_GPIO_RIGHT   GPIO_NUM_8
#define HAPTIC_GPIO_LEFT    GPIO_NUM_17
#define HAPTIC_GPIO_A       HAPTIC_GPIO_CENTER   /* alias: motor A = center  */
#define HAPTIC_GPIO_B       HAPTIC_GPIO_RIGHT    /* alias: motor B = right   */
#define HAPTIC_GPIO_C       HAPTIC_GPIO_LEFT     /* alias: motor C = left    */
/* Directional haptic drive (sensor mode). When 1, ranging_task maps obstacle
 * columns to the 3 motors each frame: col region LEFT/CENTER/RIGHT -> motor,
 * PWM duty scaled by the same squared urgency curve the buzzer uses. Set 0 to
 * keep motors silent (buzzer-only) without rewiring. Ignored in HAPTIC_TEST.
 * Design + sources: docs/research-sources/directional-haptics-mapping.md */
#define HAPTIC_DIRECTIONAL  1
/* Dominance weighting: when >=2 motors fire at once, the most-urgent keeps
 * full duty and the others are scaled by NUM/DEN (7/10). Keeps the dominant
 * direction legible -- concurrent multi-motor comprehension drops from ~99%
 * to ~70% (Zegarra Flores 2022, arXiv 2201.04453). */
#define HAPTIC_DOMINANCE_NUM 7
#define HAPTIC_DOMINANCE_DEN 10
/* Motor count + index order (used by ranging_task, which is defined above the
 * LEDC infrastructure block — declared here so it's in scope early). Order
 * matches the A/B/C aliases = { CENTER, RIGHT, LEFT }. */
#define HAPTIC_N            3
#define HAPTIC_IDX_CENTER   0             /* GPIO7  forehead */
#define HAPTIC_IDX_RIGHT    1             /* GPIO15 right temple */
#define HAPTIC_IDX_LEFT     2             /* GPIO16 left temple */
/* ERM dead-zone floor. Coin motors don't spin below ~50% duty (not enough
 * torque to beat static friction), so a pure squared curve leaves the motor
 * silent across most of the alert band and only "wakes up" point-blank --
 * which felt like "nothing until ~20 cm, then suddenly very strong". With the
 * floor, an alerting motor jumps straight to HAPTIC_DUTY_MIN (just-felt) the
 * instant the buzzer fires, and the squared curve then ramps it MIN->MAX as
 * the obstacle closes. Tune to your motor's measured start-spin duty. */
#define HAPTIC_DUTY_MIN     130           /* ~51% of 255; raise if still weak at threshold */
#define OBSTACLE_THRESHOLD_MM 600        /* start beeping at this distance (60 cm) */
#define BEEP_MS             50           /* short beep = quieter */
#define BEEP_GAP_MIN_MS     30           /* gap at point-blank (frantic chirping) */
#define BEEP_GAP_MAX_MS     700          /* gap at threshold distance (just-noticeable, indoor-friendly) */
#define BEEP_CURVE_SQUARED  1            /* 1 = ratio^2 nonlinear (Ghaffari-style); 0 = linear */

/* â”€â”€ Sensor configuration â”€â”€â”€â”€â”€â”€â”€â”€â”€â”€â”€â”€â”€â”€â”€â”€â”€â”€â”€â”€â”€â”€â”€â”€â”€â”€â”€â”€â”€â”€â”€â”€â”€â”€â”€â”€â”€â”€â”€â”€â”€â”€â”€â”€â”€â”€â”€â”€â”€â”€ */
#define SENSOR_RESOLUTION   VL53L8CX_RESOLUTION_4X4        /* 16 zones (4× tighter σ, wider angular per zone) */
#define RANGING_FREQ_HZ     30                             /* 1-60 Hz at 4X4, 1-15 Hz at 8X8 */
#define RANGING_MODE        VL53L8CX_RANGING_MODE_CONTINUOUS
#define SHARPENER_PERCENT   5                              /* 0=off, 5=default, 99=max */
#define TARGET_ORDER        VL53L8CX_TARGET_ORDER_CLOSEST  /* CLOSEST for obstacle avoidance */
#define STATUS_FILTER_STRICT 0                             /* 1 = accept status 5 only; 0 = accept {5,6,9} */

/* Sensor is physically mounted rotated N degrees CW from "natural" body
 * orientation (top of FoV = head up, bottom = ground). Stream functions
 * remap zone indices so the transmitted grid is always in body-frame:
 *   output row 0 = top of FoV (looking up)
 *   output row N-1 = bottom of FoV (looking down)
 *   output col 0 = left of body
 *   output col N-1 = right of body
 * If the rendered view is wrong, flip this to 90, 180, 270, or 0. */
/* ⚠ 2026-08-16: was 270 for the old stacked top/bottom mounting. The pod is
 * now the left/right ±22.5° pair; the Stage-3 calibration consumed the raw
 * grid with NO rotation and solved within ~1° of CAD, so raw order is already
 * body-sane. Set 0; VERIFY with the phone/desktop viewer on first flash. */
#define MOUNT_ROTATION_DEG  0

/* Optical-axis pitch below horizontal when helmet is worn level (degrees).
 * 2026-08-16: BOTH sensors are in the ±22.5° yaw pair with the whole group
 * tilted 22.5° DOWN (CAD-verified to 0.003°), so both use the same pitch.
 * Used to convert the sensor's reported distance to body-frame forward
 * distance for the obstacle-alert logic. Raw DATA: stream is NOT affected.
 *
 * ⚠ DISTANCE SEMANTICS (verified 2026-08-16 against 23 planar poses + ST
 * staff on the record): distance_mm is the PERPENDICULAR (optical-axis Z)
 * distance, NOT slant range along the zone ray. The radial→perpendicular
 * conversion happens ON-CHIP. See compute_row_cos_table() for the corrected
 * projection math. */
#define MOUNT_PITCH_DEG     22.5f    /* sensor A (wearer left): group tilt */
#define MOUNT_PITCH_DEG_TOP 22.5f    /* sensor B (wearer right): same group tilt
                                      * (name kept from the old top/bottom rig
                                      * to avoid a risky mass rename) */
#define MAX_GRID_SIDE       8

/* â”€â”€ Display options â”€â”€â”€â”€â”€â”€â”€â”€â”€â”€â”€â”€â”€â”€â”€â”€â”€â”€â”€â”€â”€â”€â”€â”€â”€â”€â”€â”€â”€â”€â”€â”€â”€â”€â”€â”€â”€â”€â”€â”€â”€â”€â”€â”€â”€â”€â”€â”€â”€â”€â”€â”€â”€â”€â”€ */
#define PRINT_GRID          0
#define PRINT_CLOSEST_ONLY  0
#define STREAM_DATA         1
#define STREAM_SIGMA        1
#define STREAM_STATUS       1     /* per-zone raw target_status codes */
#define MAX_DISTANCE_MM     4000

/* â”€â”€ WiFi / TCP â”€â”€â”€â”€â”€â”€â”€â”€â”€â”€â”€â”€â”€â”€â”€â”€â”€â”€â”€â”€â”€â”€â”€â”€â”€â”€â”€â”€â”€â”€â”€â”€â”€â”€â”€â”€â”€â”€â”€â”€â”€â”€â”€â”€â”€â”€â”€â”€â”€â”€â”€â”€â”€â”€â”€â”€â”€â”€â”€â”€ */
#define MAX_WIFI_RETRY      10
#define WIFI_CONNECTED_BIT  BIT0
#define STREAM_BUF_SIZE     512
#define MAX_TCP_CLIENTS     4         /* visualizer + measure.py + headroom */

static const char *TAG = "VL53L8CX";

static EventGroupHandle_t s_wifi_event_group = NULL;
static int s_retry_num = 0;

/* TCP client state â€” fan-out streaming to up to MAX_TCP_CLIENTS clients
 * simultaneously so the visualizer can stay live while measure.py also
 * captures. tcp_write iterates over slots; failed sends self-evict. */
static int g_client_socks[MAX_TCP_CLIENTS];
static SemaphoreHandle_t g_client_mutex = NULL;

/* Nearest valid zone FORWARD distance in mm (i.e. perpendicular z projected
 * onto the body's horizontal forward axis using the per-row cosine table),
 * updated by ranging_task each frame. 32-bit reads/writes are atomic on
 * ESP32-S3, so no mutex needed. INT16_MAX = no valid zone yet. */
static volatile int16_t g_nearest_mm = INT16_MAX;

/* True if any zone's forward distance is below its row's threshold this
 * frame. Buzzer fires on this flag, not on a single global threshold,
 * because lower rows need larger thresholds — their FoV exits BEFORE the
 * obstacle reaches body proximity, so the alert has to fire while the
 * obstacle is still in view. */
static volatile bool g_alert_active = false;
/* Master enable for motors + buzzer, driven by the HAPTIC_SWITCH_GPIO toggle.
 * true = normal; false = paused (sensor keeps streaming) for debugging. */
static volatile bool g_haptics_enabled = true;

/* Most-urgent alerting zone this frame, used for beep-rate interpolation:
 *   urgency_ratio = g_urgency_forward / g_urgency_threshold  (0..1)
 *   0   = obstacle at body (fastest beep)
 *   1   = obstacle exactly at its row's threshold (slowest beep)
 * Comparing zones by ratio (not absolute mm) means a lower-row obstacle at
 * 50 cm forward (high urgency, 50/90 = 0.56) beeps faster than an upper-row
 * obstacle at 50 cm forward (lower urgency, 50/60 = 0.83). */
static volatile int16_t g_urgency_forward   = 0;
static volatile int16_t g_urgency_threshold = 1;   /* 1 to avoid div-by-zero */

/* Per-row forward-distance threshold (mm). Output rows are body-frame after
 * the rotation remap: row 0 = top of view (overhead/head), row 7 = bottom
 * (body/waist). Larger thresholds for lower rows give the alert time to
 * fire before the obstacle exits FoV.
 *
 * Logic: row 7 with 20° pitch looks at 32–42° below horizontal, exits the
 * FoV at horizontal ~70 cm forward for belly-button-height obstacles.
 * Setting row 7 threshold to 1200 mm means the alert fires while obstacle
 * is still ~100 cm forward — comfortably in view, comfortably actionable.
 */
/* Per-row alert thresholds. Non-const because we pick 4x4 vs 8x8 set at
 * runtime (preprocessor can't evaluate the ULD's casted resolution macros).
 * Initialised in compute_row_cos_table() once we know `side`. */
static int16_t g_row_threshold_mm[MAX_GRID_SIDE];
static const int16_t g_row_threshold_8x8[MAX_GRID_SIDE] = {
    600, 600, 600, 600, 700, 800, 850, 900,
};
static const int16_t g_row_threshold_4x4[MAX_GRID_SIDE] = {
    600,    /* 4x4 row 0 — top of FoV (head + above) */
    600,    /* 4x4 row 1 — upper middle (head/chest area) */
    800,    /* 4x4 row 2 — lower middle (chest/waist area) */
    950,    /* 4x4 row 3 — bottom (waist/floor area) */
    0, 0, 0, 0,  /* unused at 4x4 */
};

/* Per-row projection table: forward_distance = distance_mm * g_row_cos[row].
 * Built once at startup from MOUNT_PITCH_DEG + each row's elevation offset.
 * Row index is in body-frame (post-rotation).
 *
 * 2026-08-16 FIX: distance_mm is PERPENDICULAR (z along the optical axis),
 * not slant. The old factor cos(alpha+pitch) assumed slant and applied the
 * zone-elevation correction to a value that never contained it — biasing
 * outer rows short by up to ~8%. Correct factor for a perpendicular z:
 *     forward = z * cos(alpha+pitch) / cos(alpha)
 * (equivalently z * (cos(pitch) - tan(alpha)*sin(pitch))). The ±22.5° YAW of
 * each sensor is deliberately ignored here: it scales forward by ~cos(22.5°),
 * making alerts fire slightly EARLY, which is the safe direction. */
static float g_row_cos[MAX_GRID_SIDE];

/* Second (top/upward) sensor's per-row tables. Same structure as the bottom
 * sensor's above. Thresholds seeded equal to the bottom set for now -- TUNE
 * separately for the upward sensor's head/overhead coverage. */
static const int16_t g_row_threshold_top_8x8[MAX_GRID_SIDE] = {
    600, 600, 600, 600, 700, 800, 850, 900,
};
static const int16_t g_row_threshold_top_4x4[MAX_GRID_SIDE] = {
    600, 600, 800, 950,    /* TODO TUNE for the upward sensor */
    0, 0, 0, 0,
};
static int16_t g_row_threshold_top[MAX_GRID_SIDE];
static float   g_row_cos_top[MAX_GRID_SIDE];

/* Latest frame's forward-distance grid (rotation + pitch projection applied),
 * 64 zones max. -1 = invalid. Read by /api/status web handler. */
static volatile int16_t g_latest_forward[MAX_GRID_SIDE * MAX_GRID_SIDE];
/* Latest frame's raw per-zone status code (0-255), in body-frame order.
 * Exposed via /api/status so the viewer can show WHY a zone is invalid
 * (status 7 = rate-consistency fail, 11 = no target detected, etc. per
 * ST UM3109 §5.5). */
static volatile uint8_t g_latest_status[MAX_GRID_SIDE * MAX_GRID_SIDE];
static volatile int     g_latest_grid_side = 0;
/* TOP sensor's body-frame grid, for the phone viewer's second heatmap. */
static volatile int16_t g_latest_forward_top[MAX_GRID_SIDE * MAX_GRID_SIDE];
static volatile uint8_t g_latest_status_top[MAX_GRID_SIDE * MAX_GRID_SIDE];

static void compute_row_cos_table(int side)
{
    float deg_per_zone = 45.0f / (float)side;
    float pitch_rad    = MOUNT_PITCH_DEG * (float)M_PI / 180.0f;
    for (int r = 0; r < side; r++) {
        /* alpha_row: elevation of this row's center relative to optical axis.
         * Row 0 (top of body view) = looking UP from optical axis = negative.
         * Row N-1 (bottom) = looking DOWN from optical axis = positive. */
        float alpha_rad = ((float)r - (side - 1) / 2.0f)
                          * deg_per_zone * (float)M_PI / 180.0f;
        /* perpendicular-distance semantics: divide out the cos(alpha) the old
         * slant model wrongly assumed was present (see table comment above) */
        g_row_cos[r]    = cosf(alpha_rad + pitch_rad) / cosf(alpha_rad);
    }

    /* Pick the per-row threshold set for this resolution */
    const int16_t *src = (side == 8) ? g_row_threshold_8x8 : g_row_threshold_4x4;
    for (int r = 0; r < MAX_GRID_SIDE; r++) {
        g_row_threshold_mm[r] = src[r];
    }
}

/* Same as compute_row_cos_table() but for the TOP/upward sensor: uses
 * MOUNT_PITCH_DEG_TOP and fills g_row_cos_top / g_row_threshold_top. */
static void compute_top_cos_table(int side)
{
    float deg_per_zone = 45.0f / (float)side;
    float pitch_rad    = MOUNT_PITCH_DEG_TOP * (float)M_PI / 180.0f;
    for (int r = 0; r < side; r++) {
        float alpha_rad = ((float)r - (side - 1) / 2.0f)
                          * deg_per_zone * (float)M_PI / 180.0f;
        /* same perpendicular-distance fix as compute_row_cos_table() */
        g_row_cos_top[r] = cosf(alpha_rad + pitch_rad) / cosf(alpha_rad);
    }
    const int16_t *src = (side == 8) ? g_row_threshold_top_8x8 : g_row_threshold_top_4x4;
    for (int r = 0; r < MAX_GRID_SIDE; r++) {
        g_row_threshold_top[r] = src[r];
    }
}
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
void app_main(void)
{
    ESP_LOGI(TAG, "VL53L8CX + WiFi interface starting");

    /* SAFETY: force all 3 haptic GPIOs to OUTPUT-LOW at the very start of boot,
     * BEFORE anything else can configure them. Prevents a "stuck-on motor"
     * after a reboot where the GPIO would otherwise be high-Z and the
     * transistor base could float into a partially-conducting state.
     * Runs regardless of HAPTIC_TEST so even normal sensor firmware
     * guarantees motors are off. */
    const gpio_num_t haptic_pins_off[] = { HAPTIC_GPIO_A, HAPTIC_GPIO_B, HAPTIC_GPIO_C };
    for (size_t i = 0; i < sizeof(haptic_pins_off)/sizeof(haptic_pins_off[0]); i++) {
        gpio_config_t cfg = {
            .pin_bit_mask = 1ULL << haptic_pins_off[i],
            .mode         = GPIO_MODE_OUTPUT,
            .pull_up_en   = GPIO_PULLUP_DISABLE,
            .pull_down_en = GPIO_PULLDOWN_ENABLE,
            .intr_type    = GPIO_INTR_DISABLE,
        };
        gpio_config(&cfg);
        gpio_set_level(haptic_pins_off[i], 0);
    }

    g_client_mutex = xSemaphoreCreateMutex();
    for (int i = 0; i < MAX_TCP_CLIENTS; i++) {
        g_client_socks[i] = -1;
    }

#if HAPTIC_TEST
    ESP_LOGW(TAG, "HAPTIC_TEST mode: sensor ranging SKIPPED. WiFi + OTA stay up "
                  "so you can OTA back to normal (set HAPTIC_TEST 0).");
#else
#if HAPTIC_DIRECTIONAL
    /* Configure the haptic LEDC channels before ranging starts driving them.
     * Re-uses the same pins the safety block just set OUTPUT-LOW; LEDC takes
     * over each pin with duty 0, so motors stay off until an obstacle alerts. */
    haptic_motors_init();
#endif

    /* Start the ranging task FIRST so the sensor can complete its I2C init
     * (about ~1 s of ULD firmware upload) BEFORE WiFi spins up. Otherwise
     * the WiFi current spike can brown the sensor's 5V rail and the I2C
     * is-alive check fails. */
    xTaskCreate(ranging_task, "ranging", 8192, NULL, 5, NULL);

    /* Give the sensor a head start before bringing up WiFi. */
    vTaskDelay(pdMS_TO_TICKS(2500));
#endif

    /* NVS is required by the WiFi driver to store its config. */
    esp_err_t ret = nvs_flash_init();
    if (ret == ESP_ERR_NVS_NO_FREE_PAGES || ret == ESP_ERR_NVS_NEW_VERSION_FOUND) {
        ESP_ERROR_CHECK(nvs_flash_erase());
        ret = nvs_flash_init();
    }
    ESP_ERROR_CHECK(ret);

    /* Start WiFi (async â€” connection completes in the background). */
    wifi_init_sta();

    /* TCP server task waits for WiFi internally, then listens. */
    xTaskCreate(tcp_server_task, "tcp_server", 4096, NULL, 4, NULL);

#if HAPTIC_TEST
    /* Motor ramp instead of the buzzer/sensor alert loop. */
    xTaskCreate(haptic_test_task, "haptic_test", 4096, NULL, 2, NULL);
#elif BUZZER_TEST
    /* Buzzer / GPIO control task. 4096 byte stack â€” 2048 was overflowing. */
    xTaskCreate(buzzer_task, "buzzer", 4096, NULL, 2, NULL);
#endif

    /* OTA rollback safety: confirm this image works (WiFi + sensor both up)
     * within ~30 s of boot, else bootloader auto-reverts to previous slot. */
    xTaskCreate(ota_rollback_confirm_task, "ota_confirm", 4096, NULL, 3, NULL);
}

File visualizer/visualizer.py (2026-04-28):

"""
VL53L8CX live 3D point cloud visualiser - v5 (+ experimental 6-DOF pose).

v5 adds an experimental relative pose estimator (Kabsch / SVD-based rigid
registration on consecutive point clouds) that integrates per-frame
deltas into a cumulative sensor pose, and draws the resulting trajectory
trail behind the sensor body. See visualizer/pose_estimator.py for the
algorithm and its limits.

v4 (carried forward) added back the scientific look from the matplotlib
version while keeping the GPU-accelerated PyQtGraph engine:

  - Side colour bar showing the distance scale (mm) like matplotlib's cbar.
  - Coloured X / Depth / Y axis arrows with text labels at the endpoints.
  - Tick text every 1000 mm along the depth axis.
  - Sensor body modelled as a flat dark rectangle at the origin with a
    bright lens ring, so you can see where the sensor is relative to the
    points.
  - Field-of-view frustum drawn as 4 corner rays + a back square at the
    far range, marking the 45 deg horizontal/vertical FoV (65 deg diagonal)
    quoted in the ST datasheet.
  - One animated ToF beam per zone, updated every frame, fading from the
    sensor lens out to each measured point in the same colour as that
    point. Invalid zones (firmware sentinel == MAX_DISTANCE_MM) drop their
    alpha to zero so they don't render.

Carried over from v3:
  - Threaded serial reader (GUI never blocks on readline).
  - Drain-first pipeline (newest valid frame is what gets rendered).
  - EMA alpha = 0.6 (settles 95 percent in ~3 frames at 10 Hz).
  - Phantom back-wall (4000 mm clamps) hidden via per-zone alpha.
"""

import argparse
import sys
from collections import deque

import numpy as np
import serial
import pyqtgraph as pg
import pyqtgraph.opengl as gl
from pyqtgraph.Qt import QtCore, QtGui, QtWidgets

from pose_estimator import RelativePoseEstimator


# ── Sensor geometry (per ST VL53L8CX datasheet) ─────────────────────────
ZONES_PER_SIDE   = 8
TOTAL_ZONES      = ZONES_PER_SIDE * ZONES_PER_SIDE
FOV_DEG_PER_AXIS = 45.0           # 65 deg diagonal, 45 deg horizontal/vertical
ANGLE_PER_ZONE   = np.radians(FOV_DEG_PER_AXIS / ZONES_PER_SIDE)

EMA_ALPHA        = 0.6
INVALID_CLAMP_MM = 4000           # firmware sentinel for invalid zones


def precompute_zone_directions():
    directions = np.zeros((TOTAL_ZONES, 3))
    centre = (ZONES_PER_SIDE - 1) / 2.0
    for row in range(ZONES_PER_SIDE):
        for col in range(ZONES_PER_SIDE):
            h = (col - centre) * ANGLE_PER_ZONE
            v = (row - centre) * ANGLE_PER_ZONE
            x =  np.sin(h)
            y = -np.sin(v)
            z =  np.cos(h) * np.cos(v)
            directions[row * ZONES_PER_SIDE + col] = (x, y, z)
    return directions


def parse_data_line(line):
    if not line.startswith("DATA:"):
        return None
    try:
        values = [int(v) for v in line[5:].split(",")]
    except ValueError:
        return None
    if len(values) != TOTAL_ZONES:
        return None
    return np.asarray(values, dtype=float)


# ── Background serial reader ─────────────────────────────────────────────
class SerialReader(QtCore.QThread):
    new_frame = QtCore.pyqtSignal(object)
    error     = QtCore.pyqtSignal(str)

    def __init__(self, port, baud):
        super().__init__()
        self.port  = port
        self.baud  = baud
        self._stop = False

    def run(self):
        try:
            ser = serial.Serial(self.port, self.baud, timeout=1)
        except serial.SerialException as exc:
            self.error.emit(str(exc))
            return

        while not self._stop:
            latest = None
            line = ser.readline().decode("utf-8", errors="ignore").strip()
            parsed = parse_data_line(line)
            if parsed is not None:
                latest = parsed

            while ser.in_waiting:
                line = ser.readline().decode("utf-8", errors="ignore").strip()
                parsed = parse_data_line(line)
                if parsed is not None:
                    latest = parsed

            if latest is not None:
                self.new_frame.emit(latest)

        ser.close()

    def stop(self):
        self._stop = True


# ── Main window ──────────────────────────────────────────────────────────
class PointCloudWindow(QtWidgets.QMainWindow):
    def __init__(self, max_mm):
        super().__init__()
        self.max_mm     = max_mm
        self.directions = precompute_zone_directions()
        self.smoothed   = None
        self.frame_n    = 0

        self.setWindowTitle("VL53L8CX live point cloud  -  v6 (world-frame memory)")
        self.resize(1300, 850)

        # Experimental 6-DOF relative pose estimator + trail buffer
        self.pose_estimator = RelativePoseEstimator()
        self.world_trail    = deque(maxlen=int(15 * 5))    # ~5 s at 15 Hz
        # Accumulated world-frame point cloud (each entry: (Nx3 world points, Nx4 RGBA))
        # Capped at ~6 s so old observations fade out before the pose drift shows.
        self.world_cloud    = deque(maxlen=int(15 * 6))

        # Central layout: GL view + side colour bar
        central = QtWidgets.QWidget()
        central.setStyleSheet("background-color: #0a0a0a;")
        h = QtWidgets.QHBoxLayout(central)
        h.setContentsMargins(0, 0, 0, 0)
        h.setSpacing(0)
        self.setCentralWidget(central)

        self.view = gl.GLViewWidget()
        self.view.setBackgroundColor((10, 10, 10))
        self.view.opts["distance"]  = max_mm * 1.7
        self.view.opts["elevation"] = 18
        self.view.opts["azimuth"]   = -65
        h.addWidget(self.view, stretch=1)

        self._build_colorbar(h, max_mm)

        # Status bar - frame counter and stats
        self.status = self.statusBar()
        self.status.setStyleSheet("color: #cccccc; background-color: #0a0a0a;")
        self.status.showMessage("Waiting for data...")

        self.cmap = pg.colormap.get("viridis")

        # Build all the static and dynamic GL items
        self._build_floor_grid()
        self._build_axes(max_mm)
        self._build_sensor_body(max_mm)
        self._build_fov_frustum(max_mm)
        self._build_rays_and_scatter()
        self._build_trajectory_trail()

    # ── Side colour bar (ImageItem with viridis gradient) ────────────────
    def _build_colorbar(self, parent_layout, max_mm):
        cbar_widget = pg.GraphicsLayoutWidget()
        cbar_widget.setBackground((10, 10, 10))
        cbar_widget.setFixedWidth(120)
        plot = cbar_widget.addPlot()
        plot.setMouseEnabled(False, False)
        plot.setMenuEnabled(False)
        plot.hideAxis("left")
        plot.hideAxis("bottom")
        plot.showAxis("right")
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

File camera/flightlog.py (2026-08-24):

"""Flight logging: FP/hour metric + intervention clips (the measurement
layer). Design: docs/plans/PLAN-fp-hour-intervention-logging.md.

- events.jsonl: every spoken alert, audio toggle, FP vote, clip, heartbeat
- FP votes: implicit (user hushes audio within FP_WINDOW_S of a caution)
  and explicit (voice "wrong" / key x)
- 60 s rolling rings (2 fps 360p JPEG, ToF grids, 20 Hz IMU) dumped to a
  clip dir on trigger: override / explicit / manual / disagreement /
  directive. openpilot pattern at fleet-size 1.
- session_report.py turns sessions into FP/hour + alerts/hour numbers.

Privacy stance (UTILITY-ROADMAP): no persistent recording — the ring
lives in RAM and persists ONLY on explicit trigger events; sessions are
local-only and git-ignored.
"""

import json
import pathlib
import threading
import time
from collections import deque

import cv2
import numpy as np

_HERE = pathlib.Path(__file__).resolve().parent
SESS_ROOT = _HERE / "sessions"
FP_WINDOW_S = 10.0        # hush within this of a caution = implicit FP vote
CLIP_DEBOUNCE_S = 30.0    # global: at most one clip per this
DISAGREE_GAP_S = 120.0    # disagreement clips: a bad scene must not fill disk
HEARTBEAT_S = 60.0

_lock = threading.Lock()
_dir = None
_events = None
_last_alert = None        # (t, key, tier)
_last_clip = 0.0
_last_disagree = 0.0
_last_hb = 0.0
_last_frame_t = 0.0

_frames = deque(maxlen=120)              # (t, jpeg bytes) ~2 fps x 60 s
_tof = {"A": deque(), "B": deque()}      # (t, grid) trimmed to 60 s
_imu = deque(maxlen=1200)                # (t, w, x, y, z) ~20 Hz x 60 s
_imu_last_t = 0.0


def start_session(meta):
    global _dir, _events
    _dir = SESS_ROOT / time.strftime("%Y-%m-%d_%H%M%S")
    (_dir / "clips").mkdir(parents=True, exist_ok=True)
    (_dir / "meta.json").write_text(json.dumps(meta, indent=1))
    _events = _dir / "events.jsonl"
    event("session_start")
    print(f"flightlog: {_dir}")


def event(kind, **fields):
    if _events is None:
        return
    fields["e"] = kind
    fields["t"] = round(time.time(), 2)
    line = json.dumps(fields)
    with _lock:
        try:
            with open(_events, "a", encoding="utf-8") as f:
                f.write(line + "\n")
        except OSError:
            pass


def heartbeat():
    global _last_hb
    now = time.time()
    if now - _last_hb >= HEARTBEAT_S:
        _last_hb = now
        event("heartbeat")


def spoken(text, key, tier, range_mm):
    """Hooked in speech_worker AFTER the filter gauntlet — logs exactly
    what the user hears. Directive utterances always earn a clip."""
    global _last_alert
    event("spoken", text=text, key=str(key), tier=tier,
          range_mm=round(float(range_mm), 0) if range_mm else None)
    if tier in ("caution", "directive"):
        _last_alert = (time.time(), str(key), tier)
        if tier == "directive":
            trigger_clip("directive")


def add_frame(frame):
    global _last_frame_t
    now = time.time()
    if now - _last_frame_t < 0.5:
        return
    _last_frame_t = now
    try:
        small = cv2.resize(frame, (640, 360))
        ok, jb = cv2.imencode(".jpg", small, [cv2.IMWRITE_JPEG_QUALITY, 70])
        if ok:
            _frames.append((now, jb.tobytes()))
    except cv2.error:
        pass


def add_tof(sensor, grid):
    if grid is None:
        return
    now = time.time()
    dq = _tof[sensor]
    dq.append((now, np.asarray(grid, dtype=np.float32).copy()))
    while dq and now - dq[0][0] > 60.0:
        dq.popleft()


def add_imu(w, x, y, z):
    global _imu_last_t
    now = time.time()
    if now - _imu_last_t < 0.05:          # subsample ~20 Hz
        return
    _imu_last_t = now
    _imu.append((now, w, x, y, z))
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

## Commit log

2026-04-28 Initial working interface for VL53L8CX on ESP32-S3
    - ESP-IDF project with rjrp44/vl53l8cx v4.0.0 via component manager
    - I2C init, ULD firmware upload, 8x8 continuous ranging at 10Hz
    - ASCII distance grid output over serial monitor
    - sdkconfig.defaults: stack size fix and I2C timeout enabled
    [main.c]
2026-04-28 Add streaming data output and 3D point cloud visualiser
    - main.c: STREAM_DATA mode emits "DATA:d0,d1,...,d63" per frame
    - Invalid zones clamped to MAX_DISTANCE_MM (4000) on the device side
    - visualizer/: Python script that projects 64 zones through the sensor's
    45 degree FOV into a live 3D point cloud with viridis colouring
2026-04-28 Add PROGRESS.md documenting project history and lessons learned
    Records all phases completed (firmware + 3D visualiser), wiring
    details, every bug encountered and fixed, and planned next steps
    for the assistive helmet sensor integration.
2026-04-28 Fix visualiser flicker, disappearing points, and noise (v2)
    Three root causes identified and fixed:
    - ax.clear() per frame was rebuilding all matplotlib artists 10x/s;
    when that exceeded 100ms the serial buffer backed up and the next
    readline() returned a partial line, causing skipped frames (points
    disappeared). Fixed by creating the scatter once and updating
    _offsets3d + set_array() in-place with draw_idle().
    - Serial buffer drain added so the renderer always shows the newest
    frame rather than a stale backlogged one.
    - EMA smoothing (alpha=0.3) per zone eliminates the raw +-10-30mm
    frame-to-frame sensor noise that made points jump visibly.
    [visualizer.py]
2026-04-28 Visualiser v3: rewrite on PyQtGraph + threaded serial reader
    Mouse-drag rotation lag and frame-render lag in v2 traced to mplot3d
    being software-rendered and to the serial loop running on the GUI
    thread. Rewrites the pipeline end-to-end:
    * Renderer swapped from matplotlib mplot3d to PyQtGraph
    GLViewWidget / GLScatterPlotItem (Qt + OpenGL). Rotation is now
    GPU-accelerated and decoupled from data updates.
    * Serial reader moved into a QThread; the new frame is delivered to
    the GUI via a Qt signal so readline() never blocks the event loop.
    * Drain order fixed. v2 did readline -> process -> drain, which
    always rendered the OLDEST queued frame whenever a redraw exceeded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
    [visualizer.py]
2026-04-28 Visualiser v4: scientific axes + sensor model + animated ToF rays
    v3 had the lag fixed but lost the scientific look the matplotlib
    version had. v4 restores it with PyQtGraph-native equivalents and
    adds a sensor body + per-zone ray animation:
    * Side colour bar (viridis, mm scale) restored as a pyqtgraph
    GraphicsLayoutWidget alongside the GL view, with a labelled
    right axis showing the distance scale.
    * Coloured X / Depth / Y axis arrows from the origin, with text
    labels at the endpoints and tick text every 1000 mm along the
    depth axis. Done with GLLinePlotItem + GLTextItem so the labels
    rotate with the camera.
    * Sensor body modelled as a flat dark rectangle (GLMeshI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
    [visualizer.py]
2026-04-28 Visualiser v6: world-frame point memory + fading trail
    Two complaints from the v5 demo:
    * The live cone was always pinned in front of the sensor. Past
    observations weren't preserved, so the visualisation looked
    static regardless of how the sensor moved.
    * The trajectory trail kept growing forever - eventually a thick
    yellow tangle that obscured the scene.
    Fixes:
    * Accumulated world-frame cloud. Each frame, valid sensor-frame
    points are transformed via the v5 pose estimate into world
    frame and pushed into a rolling 6-second deque. Every tick the
    whole buffer is transformed back into the CURRENT sensor frame
    and rendered with per-point alpha proportional to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
    [visualizer.py]
2026-04-28 Add v6 demo clip — final hardware-bound iteration
    10-second capture of the v6 visualiser running at 15 Hz with the
    world-frame point memory wrapping around the sensor as it pans and
    the fading trajectory trail behind it. Cut from the mid-section of
    the original 44-second screen recording, scaled to 1280x720, H.264
    with +faststart so GitHub renders an inline player on the README.
2026-04-28 Rewrite both READMEs as visual landing pages
    Root README:
    * Centred hero <video> tag of the v6 demo at the top, with
    autoplay/muted/loop/playsinline so GitHub renders an inline
    player.
    * Status badges (MCU, sensor, framework, renderer, status).
    * Hardware photo grid (close-up + side + top-down).
    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
2026-04-28 Embed videos as inline GIFs, add per-version posters, add v6 limitations section
    GitHub does not auto-embed <video> tags pointing at repo-tracked .mp4
    files - only at user-attachments uploaded via the web UI. Result: the
    three demo videos rendered as plain download links instead of inline
    players. Fix: convert each MP4 to a palette-optimised GIF (640 wide,
    12 fps, lanczos scale, bayer dither) and embed via <img>, which
    renders inline everywhere on GitHub.
    Also adds:
    * Per-version poster screenshots extracted from the videos:
    - poster_matplotlib_v2.png (v1/v2 era)
    - poster_v3.png (v3 PyQtGraph)
    - poster_v4.png (v4 scientific look + ToF beams)
    - poster_v6.png (v6 final)
    *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
2026-04-28 Add 'A note on process' — frame the AI collaboration as integration, not delegation
    Closing reflection placed between 'What's next' and 'References'.
    Names the specific design decisions worked through with Claude
    (EMA alpha, Kabsch derivation, world-frame memory cap, pose-estimator
    gates), then lists the concepts that were actually internalised vs.
    just shipped (mplot3d/GUI-thread blocking, SVD reflection guard,
    yaw unobservability, root-cause-vs-handwave limitations writing).
    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
2026-05-21 Add restart_tools.ps1 — one-click visualizer + monitor restart after ESP reset
    PowerShell script + a desktop shortcut for it ('Restart ESP Tools'). Use it
    every time the ESP resets and the existing visualizer / monitor falls over
    because the native USB-CDC re-enumerated.
    What it does:
    1. Kills any visualizer_simple.py and idf_monitor processes
    2. Launches the WiFi visualizer pointed at $EspIp:3333 (hidden console)
    3. Opens a fresh PowerShell window running 'idf.py -p $ComPort monitor'
    Config at the top of the script — edit $EspIp / $ComPort if either moves.
    Desktop shortcut created separately via WScript.Shell.
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2026-05-21 README: document v7 — WiFi streaming + OTA reflashing + new host tools
    Adds a new 'v7 — Untethered: WiFi streaming + OTA reflashing' section
    between v6's limitations and the IMU 'What's next' section. Documents:
    - range_sigma_mm now streamed as a parallel SIGMA: line per frame
    - Status filter widened from {5} to {5, 6, 9} (per ST UM3109 §5.5)
    - WiFi station + single-client TCP server on port 3333 (dual UART/TCP)
    - OTA HTTP POST /update endpoint on port 80 (with X-OTA-Token header)
    - Sensor-init-before-WiFi ordering + 2.5 s head start to avoid the
    5 V brownout that killed I2C init on early WiFi-enabled boots
    - New v7 host tools: visualizer_simple.py, measure.py, restart_tools.ps1,
    o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
2026-05-21 Switch resolution to 4x4 + fix OTA partition-table mismatch
    Resolution change:
    - main.c: SENSOR_RESOLUTION = VL53L8CX_RESOLUTION_4X4 (was 8X8). 4x4 has
    16 zones, 4x more SPADs per zone (~2x less noise), max 60 Hz instead
    of 15 Hz. Frequency kept at 8 Hz for now.
    - visualizer_simple.py: ZONES_PER_SIDE = 4 (matches firmware).
    - measure.py: TOTAL_ZONES = 16 (matches firmware).
    OTA bug fix (was: ESP_ERR_OTA_VALIDATE_FAILED / no partition available):
    - Root cause: sdkconfig.defaults updates only apply when sdkconfig is
    generated from scratch — they don't override an existing sdkconfig.
    The repo's old sdkconfig still had SINGLE_APP partition table +
    FLASHSIZE_2MB, so esp_ota_get_next_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
    [main.c, measure.py, visualizer_simple.py]
2026-05-21 README: reflect 4x4 as new default + document sdkconfig regeneration gotcha
    - Configuration knobs table: SENSOR_RESOLUTION default is now 4X4
    (16 zones, ~2x lower per-zone noise from 4x more SPADs averaged);
    noted that 8X8 is the alternative if you want finer spatial detail.
    - Added a 'Gotcha if you change the partition table or flash size
    mid-project' subsection right after the Credentials setup, covering
    the sdkconfig.defaults-doesn't-override-existing-sdkconfig issue
    that broke OTA during v7 dev. Documents the symptom
    (esp_ota_get_next_update_partition() returns NULL) and the fix
    (rm sdkconfig + rebuild + one USB flash).
2026-05-21 restart_tools.ps1: replace Unicode glyphs with ASCII to fix parser error
    Original script used checkmark and arrow Unicode characters in the
    success lines (e.g. '✓ Visualizer launched ... → 192.168.1.228:3333').
    The file got saved with an encoding that PowerShell parsed as broken
    string terminators — the desktop shortcut failed silently because the
    script wouldn't parse. Replaced with [OK] tags and '--' separators
    that round-trip through any encoding.
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2026-05-22 Switch back to 8x8 @ 15 Hz (max Hz allowed at 8x8 resolution)
    8x8 gives 64 zones (4x more spatial detail than 4x4) at the cost of
    ~2x higher per-zone noise (fewer SPADs averaged per zone). Frequency
    capped at 15 Hz by the ULD for 8x8 mode — still well above the 10 Hz
    walking-helmet minimum, so reactivity is fine.
    Host scripts updated to match: visualizer_simple ZONES_PER_SIDE=8,
    measure.py TOTAL_ZONES=64. Pushed wirelessly via OTA — verified 15.2 Hz
    + 64/64 valid zones post-reboot.
    [main.c, measure.py, visualizer_simple.py]
2026-05-22 Add buzzer test task on GPIO 6 (1 Hz cadence, 200 ms on / 800 ms off)
    Standalone FreeRTOS task that toggles BUZZER_GPIO (default GPIO 6) at 1 Hz.
    Set BUZZER_TEST to 0 to silence. Independent of the sensor pipeline —
    runs even if I2C init fails. GPIO 5 (PWREN) untouched; the buzzer is on
    its own dedicated pin so it doesn't interfere with sensor power control.
    [main.c]
2026-05-22 Fix buzzer task stack overflow: 2048 -> 4096 bytes + simplify to single pin
    The buzzer task was crash-looping the entire ESP every ~2 seconds because the
    2048-byte FreeRTOS stack overflowed during the GPIO sweep + ESP_LOGI call.
    Every visible 'GPIO 6 at 0 V / low voltage' reading happened during the brief
    window between reboots, before the task ran again and crashed.
    Two changes:
    - Stack bumped to 4096 bytes.
    - Dropped the multi-pin diagnostic sweep; just drive BUZZER_GPIO HIGH with
    max drive capability. Much less stack pressure.
    Also re-added the xTaskCreate(buzzer_task, ...) call to app_main that had
    been dropped during an earlier edit (see prior commits).
    [main.c]
2026-05-22 Buzzer: switch to periodic mode — idle silent, 200 ms beep every 5 s
    After confirming the active buzzer works on GPIO 6 with max drive strength,
    move from the continuous-HIGH diagnostic state to a normal periodic pattern.
    Default idle is LOW (silent); a 200 ms HIGH pulse every 5 s gives an audible
    heartbeat without being annoying.
    [main.c]
2026-05-22 Connect buzzer to obstacle detection: beep when any zone < 1 m
    First real sensor-to-actuator wiring in firmware:
    - ranging_task now tracks the nearest-valid-zone distance each frame and
    publishes it to a shared volatile int16_t (g_nearest_mm). Atomic on
    ESP32-S3 — no mutex needed for a single int read/write.
    - buzzer_task polls g_nearest_mm at 10 Hz; if any zone is closer than
    OBSTACLE_THRESHOLD_MM (1000 mm = 1 m), it emits a short BEEP_MS-long
    pulse followed by BEEP_GAP_MS silence. If everything is farther than
    1 m or no valid zones exist, the buzzer stays silent.
    - Beep shortened from 200 ms to 50 ms — less audio energy per pulse,
    audibly quieter. Adjust BEEP_MS / OBSTACLE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
    [main.c]
2026-05-22 Buzzer: distance-proportional beep rate + threshold to 60 cm
    Two tweaks based on feel-testing:
    1. Beep rate now scales with how close the obstacle is. Linear interp:
    - At threshold distance: gap = BEEP_GAP_MAX_MS (400 ms, slow alert)
    - At point-blank (0 mm): gap = BEEP_GAP_MIN_MS (30 ms, frantic chirping)
    Classic obstacle-alert UX — closer = more urgent.
    2. OBSTACLE_THRESHOLD_MM 1000 -> 600 (1 m was too far; 60 cm matches
    the helmet's near-field obstacle range better).
    [main.c]
2026-05-22 README: document v8 — first sensor→actuator loop (obstacle alert buzzer)
    Adds a v8 section between v7 and the IMU 'What's next'. Documents:
    - Active buzzer on GPIO 6 with dedicated FreeRTOS task
    - Nearest-zone tracker shared between ranging and buzzer tasks via
    volatile int16_t (atomic on ESP32-S3, no mutex)
    - Distance-proportional beep rate: linear interp between
    BEEP_GAP_MAX_MS at threshold (slow alert) and BEEP_GAP_MIN_MS at
    point-blank (frantic chirping)
    - Configuration knobs (BUZZER_GPIO, OBSTACLE_THRESHOLD_MM, BEEP_MS,
    BEEP_GAP_*) and wiring table
    - Four hard-won lessons:
    * FreeRTOS task stack defaults can crash the chip silently;
    4096 bytes minimum if the task l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
2026-05-25 v9: sensor characterization sweep (17 configs x 3 distances) + analysis pipeline
    Firmware (main/main.c):
    - Multi-client TCP fan-out (up to 4 simultaneous clients) so visualizer and
    measure.py can run in parallel; per-client failure self-evicts via send()
    returning negative.
    - Stream STATUS: line per frame in addition to DATA: + SIGMA:, exposing the
    raw ST UM3109 §5.5 status code for every zone.
    - Parameterize SHARPENER_PERCENT, TARGET_ORDER, STATUS_FILTER_STRICT via
    compile-time #defines so the sweep runner can patch one line per config.
    - Wire through vl53l8cx_set_sharpener_percent() and set_target_order().
    Host tooling (visualizer/):
    - run_sweep.ps1 + run_one_test.ps1: auto-loop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
    [A1-8x8-10hz-sharp0-closest-48cm-blackfoam_20260524-175330.csv, A1-8x8-10hz-sharp0-closest-68cm-blackfoam_20260524-182742.csv, A1-8x8-10hz-sharp0-closest-89cm-b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]
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2026-05-25 README v9: first-person rewrite + test rig photos + limitations subsection + post-sweep refinements
    - Rewrote v9 narrative and all six figure captions from second-person ('your sensor...') to first-person ('I built X, I found Y'). Earlier README sections (v1-v8) were already first-person; light sweep confirmed the only remaining 'you/your' are reader-addressed instructional bits, which is correct.
    - Embedded test rig photos (rig_wide_full_setup.jpg + rig_close_sensor_and_board.jpg) inline at the top of v9 with a caption explaining the worst-case low-IR-reflectance choice.
    - Added 'Limitations of this analysis' subsection making it explicit that the static foam-board sweep proves the physical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
    [measurements.csv, measurements.summary.csv, post-rotation-test_20260525-110035.csv]
2026-05-26 README v10: helmet mount, body-frame alerts, phone-direct viewer
    Documents the v10 iteration end-to-end:
    - Firmware-side mount rotation (MOUNT_ROTATION_DEG, rotated_zone helper)
    - Wall-stare tilt calibration (calibrate_tilt.py, fitted ~13deg -> 20deg pitch after mount adjustment)
    - Per-row slant->forward conversion using pitch + per-zone elevation
    - Per-row alert thresholds (60/60/60/60/70/80/85/90 cm, top row to bottom)
    with rationale for why bottom rows need more headroom (FoV exits sooner)
    - Phone-direct web viewer (ESP serves HTML + JSON, phone connects in Safari,
    no laptop in the loop) -- replaces the Spacedesk attempt that fell over
    - Bootloader rollback (CONFIG_BOOTLOADER_APP_ROLL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
    [measurements.csv, measurements.summary.csv, wall-tilt-calib-h185cm-d81cm_20260525-113330.csv]
2026-05-26 OTA debug: revert verbose log, root cause was UART throttle not heap
    Spent the evening capturing the OTA flow over COM10 with verbose logging
    enabled. Heap stayed rock-solid throughout (237 KB free, no fragmentation),
    disproving the heap hypothesis. Real cause: VERBOSE log level produced
    ~400 B/chunk of UART output, capped OTA at UART speed (~15 KB/s vs the
    ~150 KB/s a clean OTA does). Curl's 90 s timeout then clipped the tail of
    a 930 KB transfer.
    Reverted CONFIG_LOG_DEFAULT_LEVEL_VERBOSE -> CONFIG_LOG_DEFAULT_LEVEL_INFO.
    Kept the OTA-handler heap-progress logs in main.c -- they're INFO level
    and produce ~5 lines per OTA, no throttle penalty. Heap snapshot still
    available live via /api/hea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
    [serial_capture.py]
2026-05-26 todo: OTA debug RESOLVED — verified OTA at 6.3s / 164 KB/s after INFO log revert
2026-05-26 Research synthesis: optimal VL53L8CX config for head-mounted ETA
    Adds docs/research-optimal-config.md — a full writeup combining:
    Phase 1: re-analysis of the v9 sweep data through a wearable-latency lens.
    Composite score = reaction-blind-zone + 4σ noise band at 1.5 m/s. Latency
    penalty (5-15 cm per frame) is 10-40× larger than σ penalty (0.4-1.7 cm).
    4×4 @ 30 Hz wins on our data; 60 Hz worth empirical testing.
    Phase 2A: ST documentation deep-dive (UM3109, DS13754, UM2884, community
    threads). ST gives almost no use-case guidance for wearables. Confirms
    CONTINUOUS mode + sharpener 5 + STRONGEST-recommended only above 100 ms
    budget (our 33 ms budget at 30 Hz means CLOSEST is defensible)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
    [wearable_score.csv]
2026-05-26 Research verification + 30 Hz freq + reaction-floor analysis + below-chest synthesis
    Firmware:
    - Bump RANGING_FREQ_HZ 20 -> 30 (literature shows latency gain
    is small vs the 75 cm human-reaction floor at 1.5 m/s, but 30 Hz
    is well-proven and saves ~5 cm/frame over 20 Hz)
    Analysis:
    - analyze_wearable.py now prints the un-beatable reaction-time floor
    (0.5s reaction * walk speed) so config comparisons stop looking
    better than physics allows
    Research verification (corrects prior synthesis):
    - VERIFIED FALSE: ETH Matrix_ToF_Drones "median of center 4 pixels
    per column" claim. Read ToF_process.c directly -- they use
    status filter {5,9} + binarize + DFS island detection + reject
    clu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
    [analyze_wearable.py, main.c]
2026-05-29 v11: directional column->motor haptic drive
    Drive the 3 helmet ERM motors (CENTER/RIGHT/LEFT = GPIO 7/15/16) from the
    live depth grid each frame, so alerts now encode direction as well as
    distance:
    - Hard regional column->motor mapping (col 0 -> LEFT, 1-2 -> CENTER,
    3 -> RIGHT; generalizes to 8x8). Per-motor most-urgent tracking reuses
    the buzzer's integer cross-product ratio math.
    - Squared duty curve with an ERM dead-zone floor (HAPTIC_DUTY_MIN=130):
    an alerting motor is felt the instant the buzzer fires and ramps to
    full at point-blank. Without the floor the motor stayed silent until
    ~20 cm because coin motors don't spin below ~50% duty.
    - Dominance weighting: with >=2 motors f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
    [main.c]
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2026-08-17 Stage 3-4: ToF-camera extrinsics, live fusion, CV + evidence-based callout engine
    - CAD-measured sensor geometry + planar-target calibration (joint rigid
    two-sensor solve, 5.5mm rms, 1.15 deg from CAD); 8mm residual diagnosed
    as signal-weighted zone centroids; FOV settled at 45 deg by measurement
    - fusion_overlay.py: zone frustums projected on the fisheye feed
    - cv_fusion.py: YOLO26n-seg + ByteTrack, mask-based zone association,
    per-zone valid-hold filtering, silence-default voice (Soundscape-derived
    suppression), proximity ticker, F9 scene query, brevity mode + trainer
    - helmet firmware: final ToF pins, perpendicular-distance cos-table fix,
    provisional haptic pins (built, not yet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
    [pod_upper_casing_prt_cmbd.3MF, upper_sensor_pod.3MF]
2026-08-17 Helmet firmware flashed; IMU live; unified viewer over WiFi; voice-guided leveling
    - cv_fusion --source helmet: TCP reader for DATA:/DATAT:/Q: (grids + IMU quat)
    - camera selected by DirectShow NAME (HBV HD CAMERA) -- indices shuffle on USB
    re-enumeration and brightness heuristics fail lens-down
    - 3D attitude inset (pod wireframe + yaw compass), artificial horizon
    - quiet generated WAV tones replace winsound.Beep (drowned the speech);
    ticker mutes during utterances; hardware buzzer cancelled
    - visualizer/imu_mount_cal.py: two-pose gravity cal, snapped to cardinal
    mount orientations (board is flat+square on the pod base)
    - visualizer/mount_level.py + cv_fusion 'l' key: ball-mount leveli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
    [cv_fusion.py, imu_mount_cal.py, mount_level.py]
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2026-08-18 All hardware complete: motors ID'd (17=L,18=C,8=R), switch GPIO3, remote motor/haptics endpoints
    - /api/motor manual pulse with ranging-drive hold; /api/haptics software mute
    - pause switch re-enabled on GPIO 3 (17's old switch config was fighting the
    motor -- compiled out, root cause of the stuck-on buzz)
    - verified motor mapping flashed via WiFi OTA after repeated USB drops
    - pre-glue diagnostic script results + WIRING.md motors/switch section
    - motor_id_test.py guided tool
    [main.c, motor_id_test.py]
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2026-08-20 Biosonar review: TTC terminal-buzz ticker, range-adaptive path cone (bug fix), locked audio band
    - ticker: rate = K/TTC, ~constant ticks-per-approach across walking speeds,
    categorical terminal trill at 0.6 s TTC, stationary user goes silent
    - path cone: fixed 15 deg was narrower than a torso at close range; now
    half-angle = atan(0.35 m / range) capped 45 deg
    - CALLOUT-PROTOCOL §9: 600/1250 Hz locked, -75 dB in the echolocation band
    - research archive: biosonar-2026-08-20.md
    [cv_fusion.py]
2026-08-21 docs: feasibility-pack verdicts (6 items), headset rec reversed to DIY wired + V30i, IDEA-BANK reframes
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2026-08-22 docs: VLM benchmark — local FAIL on GTX 1650 (20-25s), NIM llama-11b usable (2-6s, abstains correctly)
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2026-08-24 feat: gravity-frame head-clearance watch (flagship) — world-frame per-sample height, 3-of-5 vote, duck directive + firmware pattern (item 7)
    [cv_fusion.py]
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2026-08-24 fix: update default helmet IP to 192.168.1.227 (DHCP moved it) across active tools
    [cv_fusion.py, motor_id_test.py, ota_flash.py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]
2026-08-24 feat: phone viewer -> Iris PWA dashboard (Add to Home Screen fullscreen, status bar, touch remote via voice-command queue); default port off the mcp leak range
    [cv_fusion.py]
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2026-08-24 feat: dashboard SVG line icons replace emojis
    [cv_fusion.py]
2026-08-24 fix: dashboard stream auto-reconnects after server restart / iOS resume
    [cv_fusion.py]
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2026-08-24 fix: phone video via single-frame polling (iOS PWA MJPEG stalls) — always auto-starts
    [cv_fusion.py]
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2026-08-24 fix: no-store cache headers — iOS home-screen icon can never launch a stale page again
    [cv_fusion.py]
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2026-08-24 fix(voice): arm on wake word despite [unk] noise; strip [unk] before command match. fix(callouts): withhold low-conf names (wrong name worse than no name)
    [cv_fusion.py, voice.py]
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2026-08-24 feat: hand-query abstention fix; power button (2-tap, returns to Start screen); session recorder (video+mic, phone REC + voice + key c)
    [cv_fusion.py, recorder.py, voice.py]
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2026-08-24 feat(haptics): firmware /api/gain (TTL-guarded damping/standby); tight-passage auto-damp to 40%; voice 'haptics off/on' (10-min standby)
    [cv_fusion.py, main.c, voice.py]
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

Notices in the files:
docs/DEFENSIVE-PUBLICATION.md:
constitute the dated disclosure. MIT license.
